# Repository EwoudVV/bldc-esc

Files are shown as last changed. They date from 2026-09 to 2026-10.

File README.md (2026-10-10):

# BLDC ESC

i'm building a small vesc like controller for BLDC and PMSM motors. the first motor is a 26V Groschopp gearmotor, but i want the board to be useful for other motors too. Hall control first, then FOC later

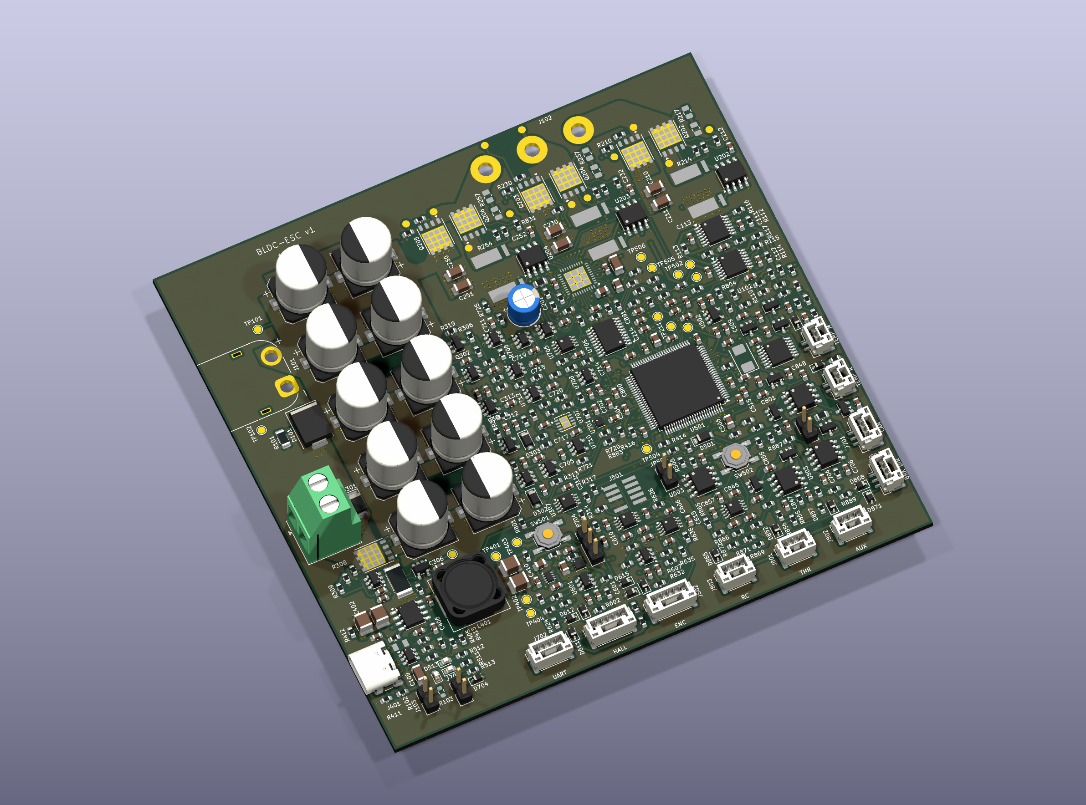
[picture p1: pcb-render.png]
PCB render


## status

the schematic and first placement are done. it's 116 x 112 mm, with all 449 parts on top. the power stage, supplies, gate control, hardware protection, current and voltage sensing, temperature inputs, Hall/encoder inputs and analog controls are routed. the CAN connector and protection, bridge test points, optional snubbers and 8MHz clock are connected too

the USB-C data pins now reach the ESD protection chip in both plug orientations. the USB shield, chassis connector and bond components are connected, and the remaining EEPROM supply pads have power. 20 connections are still open: the long USB data pair, SWD/SWO, UART, CAN logic, EEPROM signals, status LEDs, power-source status and three MCU test points

the board hasn't been built yet. routing, mounting and cooling still need work before ordering it. i'm comparing PCBWay and JLCPCB for bare boards to assemble myself. the fab and exact layer stack aren't confirmed

**don't manufacture the devlog 03 snapshot (`dcad1e4`).** the XT60 connections were backwards in that version. the current design has pad 1 as GND and pad 2 as VBUS

devlogs are on [Half Life](https://halflife.hackclub.com/projects/cmuveje4m009201rvgvsn2jbz) and synced to [JOURNAL.md](https://github.com/EwoudVV/bldc-esc/blob/main/JOURNAL.md)

## hardware

- STM32G474VET6 and DRV8353S gate driver
- six 60V bridge MOSFETs and three 1 milliohm current shunts
- INA241 current sensing, voltage sensing and temperature inputs
- hardware current protection, watchdog and brake chopper
- Hall and encoder inputs, analog throttle, RC PWM and digital controls
- CAN FD, UART, USB-C and SWD
- XT60 power input, MT60 motor pigtail and JST-GH signal connectors

## targets

- 12-30V input, mainly for 6S batteries and 24V systems
- 15A RMS phase current with passive cooling, 20A with extra cooling
- around 40A peak, with the allowed duration still to be worked out
- four layers, with 2 oz outer copper and 1 oz inner copper planned

these current ratings are targets until thermal testing is done

## test motor

Groschopp / Blue-White BL6560-PS2120, P/N 930-23-9002:

- 26V, 0.75A nameplate
- 10W reducer output, 125 RPM, 6.68 in-lb torque
- 20:1 gearbox
- three phase leads and a separate sensor wire bundle

the OEM sensor pinout and motor measurements still need checking

## files

- `bldc-esc.kicad_pro`: open this in KiCad
- `schematic/`: the circuit sheets
- `bldc-esc.kicad_sym` and `bldc-esc.pretty/`: local symbols and footprints
- [bom.csv](bom.csv): component list, including the DNP flags

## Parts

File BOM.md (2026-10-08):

# BLDC-ESC – bill of materials

<!-- Generated by Half Life from project cmuveje4m009201rvgvsn2jbz. Edits here are overwritten on the next sync. -->
<!-- Generated: 1970-01-01T00:00:00.000Z -->

> [!NOTE]
> This parts list is mirrored from [Half Life](https://halflife.hackclub.com). Editing it here will not change the platform's copy, and the next sync overwrites this file.

| Week | Tier | Parts funding |
| --- | --- | --- |
| Week 1 | Tier 3 | $100.00 |

_No parts listed yet._

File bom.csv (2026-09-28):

reference | sheet | value | MPN | manufacturer | footprint | DNP | exclude_from_BOM
J101 | 01_dc_link | XT60PW-M | XT60PW-M | AMASS | Connector_AMASS:AMASS_XT60PW-M_1x02_P7.20mm_Horizontal | false | false
D101 | 01_dc_link | SMCJ30A | SMCJ30A | Littelfuse | Diode_SMD:D_SMC | false | false
C101 | 01_dc_link | 100u 63V | GXC1J101MCW1GS | Nichicon | Capacitor_SMD:CP_Elec_10x12.5 | false | false
C102 | 01_dc_link | 100u 63V | GXC1J101MCW1GS | Nichicon | Capacitor_SMD:CP_Elec_10x12.5 | false | false
C103 | 01_dc_link | 100u 63V | GXC1J101MCW1GS | Nichicon | Capacitor_SMD:CP_Elec_10x12.5 | false | false
C104 | 01_dc_link | 100u 63V | GXC1J101MCW1GS | Nichicon | Capacitor_SMD:CP_Elec_10x12.5 | false | false
C105 | 01_dc_link | 100u 63V | GXC1J101MCW1GS | Nichicon | Capacitor_SMD:CP_Elec_10x12.5 | false | false
C106 | 01_dc_link | 100u 63V | GXC1J101MCW1GS | Nichicon | Capacitor_SMD:CP_Elec_10x12.5 | false | false
C107 | 01_dc_link | 100u 63V | GXC1J101MCW1GS | Nichicon | Capacitor_SMD:CP_Elec_10x12.5 | false | false
C115 | 01_dc_link | 100u 63V | GXC1J101MCW1GS | Nichicon | Capacitor_SMD:CP_Elec_10x12.5 | false | false
C108 | 01_dc_link | 100u 63V | GXC1J101MCW1GS | Nichicon | Capacitor_SMD:CP_Elec_10x12.5 | false | false
C116 | 01_dc_link | 100u 63V | GXC1J101MCW1GS | Nichicon | Capacitor_SMD:CP_Elec_10x12.5 | false | false
R101 | 01_dc_link | 10k | RC1206FR-0710KL | Yageo | Resistor_SMD:R_1206_3216Metric | false | false
J102 | 01_dc_link | MT60 / 12AWG pigtail | MT60-M | AMASS | bldc-esc:MT60_Pigtail_12AWG | false | false
J103 | 01_dc_link | CHASSIS | M20-9990245 | Harwin | Connector_PinHeader_2.54mm:PinHeader_1x02_P2.54mm_Vertical | false | false
R102 | 01_dc_link | 1M | RC0603FR-071ML | Yageo | Resistor_SMD:R_0603_1608Metric | false | false
C109 | 01_dc_link | 4.7n 1kV | C1206C472KDRACTU | KEMET | Capacitor_SMD:C_1206_3216Metric | false | false
R103 | 01_dc_link | 0 | RC0603JR-070RL | Yageo | Resistor_SMD:R_0603_1608Metric | true | false
TP101 | 01_dc_link | VBUS | TESTPOINT |  | TestPoint:TestPoint_Pad_D1.5mm | false | true
TP102 | 01_dc_link | GND | TESTPOINT |  | TestPoint:TestPoint_Pad_D1.5mm | false | true
TP103 | 01_dc_link | PHASE_A | TESTPOINT |  | TestPoint:TestPoint_Pad_D1.5mm | false | true
TP104 | 01_dc_link | PHASE_B | TESTPOINT |  | TestPoint:TestPoint_Pad_D1.5mm | false | true
TP105 | 01_dc_link | PHASE_C | TESTPOINT |  | TestPoint:TestPoint_Pad_D1.5mm | false | true
U201 | 12_gate_driver | DRV8353SRTAT | DRV8353SRTAT | Texas Instruments | bldc-esc:DRV8353_RTA0040B | false | false
R201 | 12_gate_driver | 2.2 | RC0805FR-072R2L | Yageo | Resistor_SMD:R_0805_2012Metric | false | false
C201 | 12_gate_driver | 22u 63V | EEUFC1J220 | Panasonic | Capacitor_THT:CP_Radial_D6.3mm_P2.50mm | false | false
C202 | 12_gate_driver | 100n 100V | C0603C104K1RACTU | KEMET | Capacitor_SMD:C_0603_1608Metric | false | false
C203 | 12_gate_driver | 47n 100V | C0805C473K1RACTU | KEMET | Capacitor_SMD:C_0805_2012Metric | false | false
C204 | 12_gate_driver | 1u 50V | C3216X7R1H105K160AB | TDK | Capacitor_SMD:C_1206_3216Metric | false | false
C205 | 12_gate_driver | 1u 25V | C0805C105K3RACTU | KEMET | Capacitor_SMD:C_0805_2012Metric | false | false
C206 | 12_gate_driver | 1u 16V | C0603C105K4RACTU | KEMET | Capacitor_SMD:C_0603_1608Metric | false | false
C207 | 12_gate_driver | 100n 50V | C0603C104K5RACTU | KEMET | Capacitor_SMD:C_0603_1608Metric | false | false
R202 | 12_gate_driver | 4.7k | RC0603FR-074K7L | Yageo | Resistor_SMD:R_0603_1608Metric | false | false
R203 | 12_gate_driver | 10k | RC0603FR-0710KL | Yageo | Resistor_SMD:R_0603_1608Metric | false | false
R204 | 12_gate_driver | 100k | RC0603FR-07100KL | Yageo | Resistor_SMD:R_0603_1608Metric | false | false
R205 | 12_gate_driver | 10k | RC0603FR-0710KL | Yageo | Resistor_SMD:R_0603_1608Metric | false | false
Q201 | 02_bridge | ISC011N06LM5 | ISC011N06LM5ATMA1 | Infineon | Package_SON:Infineon_PG-TDSON-8_6.15x5.15mm | false | false
Q202 | 02_bridge | ISC011N06LM5 | ISC011N06LM5ATMA1 | Infineon | Package_SON:Infineon_PG-TDSON-8_6.15x5.15mm | false | false
R210 | 02_bridge | 3.3 | RC0603FR-073R3L | Yageo | Resistor_SMD:R_0603_1608Metric | false | false
R211 | 02_bridge | 47k | RC0603FR-0747KL | Yageo | Resistor_SMD:R_0603_1608Metric | false | false
R212 | 02_bridge | 3.3 | RC0603FR-073R3L | Yageo | Resistor_SMD:R_0603_1608Metric | false | false
R213 | 02_bridge | 47k | RC0603FR-0747KL | Yageo | Resistor_SMD:R_0603_1608Metric | false | false
R214 | 02_bridge | 1m 1% 8W | CSS4J-4026R-1L00F | Bourns | bldc-esc:CSS4J_4026 | false | false
C210 | 02_bridge | 1u 100V | C3216X7R2A105K160AA | TDK | Capacitor_SMD:C_1206_3216Metric | false | false
C211 | 02_bridge | 1u 100V | C3216X7R2A105K160AA | TDK | Capacitor_SMD:C_1206_3216Metric | false | false
U202 | 02_bridge | INA241A2IDR | INA241A2IDR | Texas Instruments | Package_SO:SOIC-8_3.9x4.9mm_P1.27mm | false | false
C212 | 02_bridge | 100n 50V | C0603C104K5RACTU | KEMET | Capacitor_SMD:C_0603_1608Metric | false | false
R215 | 02_bridge | 100 | RC0603FR-07100RL | Yageo | Resistor_SMD:R_0603_1608Metric | false | false
C213 | 02_bridge | 1n 50V | C0603C102J5GACTU | KEMET | Capacitor_SMD:C_0603_1608Metric | false | false
TP210 | 02_bridge | I_PHASE_A | TESTPOINT |  | TestPoint:TestPoint_Pad_D1.5mm | false | true
R216 | 02_bridge | 1k | RC0603FR-071KL | Yageo | Resistor_SMD:R_0603_1608Metric | false | false
C214 | 02_bridge | 1n 50V | C0603C102J5GACTU | KEMET | Capacitor_SMD:C_0603_1608Metric | false | false
R217 | 02_bridge | 10 | RC0805FR-0710RL | Yageo | Resistor_SMD:R_0805_2012Metric | true | false
C215 | 02_bridge | 1n 100V | C0805C102J1GACTU | KEMET | Capacitor_SMD:C_0805_2012Metric | true | false
Q203 | 02_bridge | ISC011N06LM5 | ISC011N06LM5ATMA1 | Infineon | Package_SON:Infineon_PG-TDSON-8_6.15x5.15mm | false | false
Q204 | 02_bridge | ISC011N06LM5 | ISC011N06LM5ATMA1 | Infineon | Package_SON:Infineon_PG-TDSON-8_6.15x5.15mm | false | false
R230 | 02_bridge | 3.3 | RC0603FR-073R3L | Yageo | Resistor_SMD:R_0603_1608Metric | false | false
R231 | 02_bridge | 47k | RC0603FR-0747KL | Yageo | Resistor_SMD:R_0603_1608Metric | false | false
R232 | 02_bridge | 3.3 | RC0603FR-073R3L | Yageo | Resistor_SMD:R_0603_1608Metric | false | false
R233 | 02_bridge | 47k | RC0603FR-0747KL | Yageo | Resistor_SMD:R_0603_1608Metric | false | false
R234 | 02_bridge | 1m 1% 8W | CSS4J-4026R-1L00F | Bourns | bldc-esc:CSS4J_4026 | false | false
C230 | 02_bridge | 1u 100V | C3216X7R2A105K160AA | TDK | Capacitor_SMD:C_1206_3216Metric | false | false
C231 | 02_bridge | 1u 100V | C3216X7R2A105K160AA | TDK | Capacitor_SMD:C_1206_3216Metric | false | false
U203 | 02_bridge | INA241A2IDR | INA241A2IDR | Texas Instruments | Package_SO:SOIC-8_3.9x4.9mm_P1.27mm | false | false
C232 | 02_bridge | 100n 50V | C0603C104K5RACTU | KEMET | Capacitor_SMD:C_0603_1608Metric | false | false
R235 | 02_bridge | 100 | RC0603FR-07100RL | Yageo | Resistor_SMD:R_0603_1608Metric | false | false
C233 | 02_bridge | 1n 50V | C0603C102J5GACTU | KEMET | Capacitor_SMD:C_0603_1608Metric | false | false
TP211 | 02_bridge | I_PHASE_B | TESTPOINT |  | TestPoint:TestPoint_Pad_D1.5mm | false | true
R236 | 02_bridge | 1k | RC0603FR-071KL | Yageo | Resistor_SMD:R_0603_1608Metric | false | false
C234 | 02_bridge | 1n 50V | C0603C102J5GACTU | KEMET | Capacitor_SMD:C_0603_1608Metric | false | false
R237 | 02_bridge | 10 | RC0805FR-0710RL | Yageo | Resistor_SMD:R_0805_2012Metric | true | false
C235 | 02_bridge | 1n 100V | C0805C102J1GACTU | KEMET | Capacitor_SMD:C_0805_2012Metric | true | false
Q205 | 02_bridge | ISC011N06LM5 | ISC011N06LM5ATMA1 | Infineon | Package_SON:Infineon_PG-TDSON-8_6.15x5.15mm | false | false
Q206 | 02_bridge | ISC011N06LM5 | ISC011N06LM5ATMA1 | Infineon | Package_SON:Infineon_PG-TDSON-8_6.15x5.15mm | false | false
R250 | 02_bridge | 3.3 | RC0603FR-073R3L | Yageo | Resistor_SMD:R_0603_1608Metric | false | false
R251 | 02_bridge | 47k | RC0603FR-0747KL | Yageo | Resistor_SMD:R_0603_1608Metric | false | false
R252 | 02_bridge | 3.3 | RC0603FR-073R3L | Yageo | Resistor_SMD:R_0603_1608Metric | false | false
R253 | 02_bridge | 47k | RC0603FR-0747KL | Yageo | Resistor_SMD:R_0603_1608Metric | false | false
R254 | 02_bridge | 1m 1% 8W | CSS4J-4026R-1L00F | Bourns | bldc-esc:CSS4J_4026 | false | false
C250 | 02_bridge | 1u 100V | C3216X7R2A105K160AA | TDK | Capacitor_SMD:C_1206_3216Metric | false | false
C251 | 02_bridge | 1u 100V | C3216X7R2A105K160AA | TDK | Capacitor_SMD:C_1206_3216Metric | false | false
U204 | 02_bridge | INA241A2IDR | INA241A2IDR | Texas Instruments | Package_SO:SOIC-8_3.9x4.9mm_P1.27mm | false | false
C252 | 02_bridge | 100n 50V | C0603C104K5RACTU | KEMET | Capacitor_SMD:C_0603_1608Metric | false | false
R255 | 02_bridge | 100 | RC0603FR-07100RL | Yageo | Resistor_SMD:R_0603_1608Metric | false | false
C253 | 02_bridge | 1n 50V | C0603C102J5GACTU | KEMET | Capacitor_SMD:C_0603_1608Metric | false | false
TP212 | 02_bridge | I_PHASE_C | TESTPOINT |  | TestPoint:TestPoint_Pad_D1.5mm | false | true
R256 | 02_bridge | 1k | RC0603FR-071KL | Yageo | Resistor_SMD:R_0603_1608Metric | false | false
C254 | 02_bridge | 1n 50V | C0603C102J5GACTU | KEMET | Capacitor_SMD:C_0603_1608Metric | false | false
R257 | 02_bridge | 10 | RC0805FR-0710RL | Yageo | Resistor_SMD:R_0805_2012Metric | true | false
C255 | 02_bridge | 1n 100V | C0805C102J1GACTU | KEMET | Capacitor_SMD:C_0805_2012Metric | true | false
U401 | 04_power_usb | LM5164DDAR | LM5164DDAR | Texas Instruments | Package_SO:HSOP-8-1EP_3.9x4.9mm_P1.27mm_EP2.41x3.1mm_ThermalVias | false | false
R401 | 04_power_usb | 300k | RC0603FR-07300KL | Yageo | Resistor_SMD:R_0603_1608Metric | false | false
R402 | 04_power_usb | 100k | RC0603FR-07100KL | Yageo | Resistor_SMD:R_0603_1608Metric | false | false
R403 | 04_power_usb | 42.2k | RC0603FR-0742K2L | Yageo | Resistor_SMD:R_0603_1608Metric | false | false
C401 | 04_power_usb | 2.2u 100V | CGA6N3X7R2A225K230AB | TDK | Capacitor_SMD:C_1210_3225Metric | false | false
C402 | 04_power_usb | 2.2u 100V | CGA6N3X7R2A225K230AB | TDK | Capacitor_SMD:C_1210_3225Metric | false | false
C403 | 04_power_usb | 2.2n 50V | C0603C222J5GACTU | KEMET | Capacitor_SMD:C_0603_1608Metric | false | false
L401 | 04_power_usb | 68uH / Isat>=2.3A | MSS1246T-683MLC | Coilcraft | Inductor_SMD:L_Coilcraft_MSS1246T-XXX | false | false
C404 | 04_power_usb | 22u 25V | MSAST32MSB7226KPNB25 | Taiyo Yuden | Capacitor_SMD:C_1210_3225Metric | false | false
C405 | 04_power_usb | 22u 25V | MSAST32MSB7226KPNB25 | Taiyo Yuden | Capacitor_SMD:C_1210_3225Metric | false | false
R404 | 04_power_usb | 324k 0.1% | RT0603BRD07324KL | Yageo | Resistor_SMD:R_0603_1608Metric | false | false
R405 | 04_power_usb | 100k 0.1% | RT0603BRD07100KL | Yageo | Resistor_SMD:R_0603_1608Metric | false | false
R406 | 04_power_usb | 301k | RC0603FR-07301KL | Yageo | Resistor_SMD:R_0603_1608Metric | false | false
C406 | 04_power_usb | 2.2n 50V | C0603C222J5GACTU | KEMET | Capacitor_SMD:C_0603_1608Metric | false | false
C407 | 04_power_usb | 82p 50V | C0603C820J5GACTU | KEMET | Capacitor_SMD:C_0603_1608Metric | false | false
R407 | 04_power_usb | 10k | RC0603FR-0710KL | Yageo | Resistor_SMD:R_0603_1608Metric | false | false
U402 | 04_power_usb | TPS2116DRLR | TPS2116DRLR | Texas Instruments | Package_TO_SOT_SMD:SOT-583-8 | false | false
R408 | 04_power_usb | 300k | RC0603FR-07300KL | Yageo | Resistor_SMD:R_0603_1608Metric | false | false
R409 | 04_power_usb | 100k | RC0603FR-07100KL | Yageo | Resistor_SMD:R_0603_1608Metric | false | false
R410 | 04_power_usb | 10k | RC0603FR-0710KL | Yageo | Resistor_SMD:R_0603_1608Metric | false | false
C408 | 04_power_usb | 1u 16V | C0603C105K4RACTU | KEMET | Capacitor_SMD:C_0603_1608Metric | false | false
C409 | 04_power_usb | 1u 16V | C0603C105K4RACTU | KEMET | Capacitor_SMD:C_0603_1608Metric | false | false
C410 | 04_power_usb | 4.7u 25V | C0805C475K3RACTU | KEMET | Capacitor_SMD:C_0805_2012Metric | false | false
U403 | 04_power_usb | TLV75801PDRVR | TLV75801PDRVR | Texas Instruments | Package_SON:WSON-6-1EP_2x2mm_P0.65mm_EP1x1.6mm | false | false
R417 | 04_power_usb | 51.1k 0.1% | RT0603BRD0751K1L | Yageo | Resistor_SMD:R_0603_1608Metric | false | false
R418 | 04_power_usb | 10k 0.1% | RT0603BRD0710KL | Yageo | Resistor_SMD:R_0603_1608Metric | false | false
C411 | 04_power_usb | 1u 16V | C0603C105K4RACTU | KEMET | Capacitor_SMD:C_0603_1608Metric | false | false
C412 | 04_power_usb | 4.7u 25V | C0805C475K3RACTU | KEMET | Capacitor_SMD:C_0805_2012Metric | false | false
J401 | 13_usb_status | USB4105-GF-A | USB4105-GF-A | GCT | bldc-esc:USB4105_PCBWay | false | false
R411 | 13_usb_status | 5.1k | RC0603FR-075K1L | Yageo | Resistor_SMD:R_0603_1608Metric | false | false
R412 | 13_usb_status | 5.1k | RC0603FR-075K1L | Yageo | Resistor_SMD:R_0603_1608Metric | false | false
F401 | 13_usb_status | 0.5A / 6V | MF-PSMF050X-2 | Bourns | bldc-esc:MF_PSMF0805 | false | false
C413 | 13_usb_status | 100n 50V | C0603C104K5RACTU | KEMET | Capacitor_SMD:C_0603_1608Metric | false | false
U404 | 13_usb_status | USBLC6-2SC6 | USBLC6-2SC6 | STMicroelectronics | Package_TO_SOT_SMD:SOT-23-6 | false | false
R413 | 13_usb_status | 22 | RC0603FR-0722RL | Yageo | Resistor_SMD:R_0603_1608Metric | false | false
R414 | 13_usb_status | 22 | RC0603FR-0722RL | Yageo | Resistor_SMD:R_0603_1608Metric | false | false
R415 | 13_usb_status | 10k | RC0603FR-0710KL | Yageo | Resistor_SMD:R_0603_1608Metric | false | false
R416 | 13_usb_status | 15k | RC0603FR-0715KL | Yageo | Resistor_SMD:R_0603_1608Metric | false | false
TP401 | 13_usb_status | 5V_BUS | TESTPOINT |  | TestPoint:TestPoint_Pad_D1.5mm | false | true
TP402 | 13_usb_status | 5V_SYS | TESTPOINT |  | TestPoint:TestPoint_Pad_D1.5mm | false | true
TP403 | 13_usb_status | 3V3 | TESTPOINT |  | TestPoint:TestPoint_Pad_D1.5mm | false | true
TP404 | 13_usb_status | GND | TESTPOINT |  | TestPoint:TestPoint_Pad_D1.5mm | false | true
U501 | 05_mcu | STM32G474VET6 | STM32G474VET6 | STMicroelectronics | Package_QFP:LQFP-100_14x14mm_P0.5mm | false | false
C501 | 05_mcu | 100n 50V | C0603C104K5RACTU | KEMET | Capacitor_SMD:C_0603_1608Metric | false | false
C502 | 05_mcu | 100n 50V | C0603C104K5RACTU | KEMET | Capacitor_SMD:C_0603_1608Metric | false | false
C503 | 05_mcu | 100n 50V | C0603C104K5RACTU | KEMET | Capacitor_SMD:C_0603_1608Metric | false | false
C504 | 05_mcu | 100n 50V | C0603C104K5RACTU | KEMET | Capacitor_SMD:C_0603_1608Metric | false | false
C505 | 05_mcu | 100n 50V | C0603C104K5RACTU | KEMET | Capacitor_SMD:C_0603_1608Metric | false | false
C506 | 05_mcu | 4.7u 25V | C0805C475K3RACTU | KEMET | Capacitor_SMD:C_0805_2012Metric | false | false
FB501 | 05_mcu | 600R @ 100MHz | BLM18KG601SN1D | Murata | Inductor_SMD:L_0603_1608Metric | false | false
C507 | 05_mcu | 4.7u 25V | C0805C475K3RACTU | KEMET | Capacitor_SMD:C_0805_2012Metric | false | false
C508 | 05_mcu | 100n 50V | C0603C104K5RACTU | KEMET | Capacitor_SMD:C_0603_1608Metric | false | false
U502 | 05_mcu | REF2025AIDDCR | REF2025AIDDCR | Texas Instruments | Package_TO_SOT_SMD:SOT-23-5 | false | false
C509 | 05_mcu | 100n 50V | C0603C104K5RACTU | KEMET | Capacitor_SMD:C_0603_1608Metric | false | false
C510 | 05_mcu | 1u 16V | C0603C105K4RACTU | KEMET | Capacitor_SMD:C_0603_1608Metric | false | false
C511 | 05_mcu | 100n 50V | C0603C104K5RACTU | KEMET | Capacitor_SMD:C_0603_1608Metric | false | false
C512 | 05_mcu | 100n 50V | C0603C104K5RACTU | KEMET | Capacitor_SMD:C_0603_1608Metric | false | false
R501 | 05_mcu | 1k | RC0603FR-071KL | Yageo | Resistor_SMD:R_0603_1608Metric | false | false
D501 | 05_mcu | PMEG2010ER | PMEG2010ER,115 | Nexperia | Diode_SMD:Nexperia_CFP3_SOD-123W | false | false
Y501 | 05_mcu | 8MHz / CL18p | ABM3-8.000MHZ-D2Y-T | Abracon | Crystal:Crystal_SMD_Abracon_ABM3-2Pin_5.0x3.2mm | false | false
R502 | 05_mcu | 0 | RC0603JR-070RL | Yageo | Resistor_SMD:R_0603_1608Metric | false | false
C513 | 05_mcu | 27p 50V | C0603C270J5GACTU | KEMET | Capacitor_SMD:C_0603_1608Metric | false | false
C514 | 05_mcu | 27p 50V | C0603C270J5GACTU | KEMET | Capacitor_SMD:C_0603_1608Metric | false | false
R503 | 05_mcu | 100k | RC0603FR-07100KL | Yageo | Resistor_SMD:R_0603_1608Metric | false | false
JP501 | 05_mcu | BOOT0 | M20-9990245 | Harwin | Connector_PinHeader_2.54mm:PinHeader_1x02_P2.54mm_Vertical | false | false
SW501 | 05_mcu | RESET | TL3342F160QG | E-Switch | Button_Switch_SMD:SW_SPST_TL3342 | false | false
C515 | 05_mcu | 100n 50V | C0603C104K5RACTU | KEMET | Capacitor_SMD:C_0603_1608Metric | false | false
R504 | 05_mcu | 10k | RC0603FR-0710KL | Yageo | Resistor_SMD:R_0603_1608Metric | false | false
SW502 | 05_mcu | USER | TL3342F160QG | E-Switch | Button_Switch_SMD:SW_SPST_TL3342 | false | false
R505 | 05_mcu | 10k | RC0603FR-0710KL | Yageo | Resistor_SMD:R_0603_1608Metric | false | false
J501 | 05_mcu | SWD / KEY 7 | FTSH-105-01-L-DV-007-K | Samtec | bldc-esc:FTSH_105_DV_007_K | false | false
TP501 | 05_mcu | VREF_2V5 | TESTPOINT |  | TestPoint:TestPoint_Pad_D1.5mm | false | true
TP502 | 05_mcu | VBIAS_1V25 | TESTPOINT |  | TestPoint:TestPoint_Pad_D1.5mm | false | true
TP503 | 05_mcu | 3V3_A | TESTPOINT |  | TestPoint:TestPoint_Pad_D1.5mm | false | true
TP504 | 05_mcu | ADC_TRIG_SCOPE | TESTPOINT |  | TestPoint:TestPoint_Pad_D1.5mm | false | true
TP505 | 05_mcu | DAC1_CH1_TP | TESTPOINT |  | TestPoint:TestPoint_Pad_D1.5mm | false | true
TP506 | 05_mcu | DAC1_CH2_TP | TESTPOINT |  | TestPoint:TestPoint_Pad_D1.5mm | false | true
U301 | 03_regen | TLV3011BIDBVR | TLV3011BIDBVR | Texas Instruments | Package_TO_SOT_SMD:SOT-23-6 | false | false
R301 | 03_regen | 100k 0.1% | RT0603BRD07100KL | Yageo | Resistor_SMD:R_0603_1608Metric | false | false
R302 | 03_regen | 100k 0.1% | RT0603BRD07100KL | Yageo | Resistor_SMD:R_0603_1608Metric | false | false
R303 | 03_regen | 8.45k 0.1% | RT0603BRD078K45L | Yageo | Resistor_SMD:R_0603_1608Metric | false | false
R304 | 03_regen | 10k 0.1% | RT0603BRD0710KL | Yageo | Resistor_SMD:R_0603_1608Metric | false | false
R305 | 03_regen | 2.49M | RC0603FR-072M49L | Yageo | Resistor_SMD:R_0603_1608Metric | false | false
R306 | 03_regen | 4.7k | RC0603FR-074K7L | Yageo | Resistor_SMD:R_0603_1608Metric | false | false
C301 | 03_regen | 1n 50V | C0603C102J5GACTU | KEMET | Capacitor_SMD:C_0603_1608Metric | false | false
C302 | 03_regen | 100n 50V | C0603C104K5RACTU | KEMET | Capacitor_SMD:C_0603_1608Metric | false | false
C303 | 03_regen | 100n 50V | C0603C104K5RACTU | KEMET | Capacitor_SMD:C_0603_1608Metric | false | false
U308 | 03_regen | REF2025AIDDCR | REF2025AIDDCR | Texas Instruments | Package_TO_SOT_SMD:SOT-23-5 | false | false
C313 | 03_regen | 100n 50V | C0603C104K5RACTU | KEMET | Capacitor_SMD:C_0603_1608Metric | false | false
C314 | 03_regen | 1u 16V | C0603C105K4RACTU | KEMET | Capacitor_SMD:C_0603_1608Metric | false | false
U302 | 03_regen | UCC27511ADBVR | UCC27511ADBVR | Texas Instruments | Package_TO_SOT_SMD:SOT-23-6 | false | false
R307 | 03_regen | 2.2 | RC0603FR-072R2L | Yageo | Resistor_SMD:R_0603_1608Metric | false | false
R308 | 03_regen | 1 | RC0603FR-071RL | Yageo | Resistor_SMD:R_0603_1608Metric | false | false
Q301 | 03_regen | ISC011N06LM5 | ISC011N06LM5ATMA1 | Infineon | Package_SON:Infineon_PG-TDSON-8_6.15x5.15mm | false | false
R309 | 03_regen | 47k | RC0603FR-0747KL | Yageo | Resistor_SMD:R_0603_1608Metric | false | false
R310 | 03_regen | 3m / 3W | WSLP2512R0030FEA | Vishay | Resistor_SMD:R_2512_6332Metric | false | false
C304 | 03_regen | 100n 50V | C0603C104K5RACTU | KEMET | Capacitor_SMD:C_0603_1608Metric | false | false
C305 | 03_regen | 1u 16V | C0603C105K4RACTU | KEMET | Capacitor_SMD:C_0603_1608Metric | false | false
J301 | 03_regen | DUMP RESISTOR | 1711725 | Phoenix Contact | TerminalBlock_Phoenix:TerminalBlock_Phoenix_MKDS-3-2-5.08_1x02_P5.08mm_Horizontal | false | false
D301 | 03_regen | STPS5H100AF | STPS5H100AF | STMicroelectronics | Diode_SMD:D_SOD-128 | false | false
U303 | 03_regen | INA180A1IDBVR | INA180A1IDBVR | Texas Instruments | Package_TO_SOT_SMD:SOT-23-5 | false | false
C306 | 03_regen | 100n 50V | C0603C104K5RACTU | KEMET | Capacitor_SMD:C_0603_1608Metric | false | false
U304 | 15_regen_safety | TLV3201AIDBVR | TLV3201AIDBVR | Texas Instruments | Package_TO_SOT_SMD:SOT-23-5 | false | false
C307 | 15_regen_safety | 100n 50V | C0603C104K5RACTU | KEMET | Capacitor_SMD:C_0603_1608Metric | false | false
R311 | 15_regen_safety | 10k | RC0603FR-0710KL | Yageo | Resistor_SMD:R_0603_1608Metric | false | false
U305 | 15_regen_safety | TPS3808G50DBVR | TPS3808G50DBVR | Texas Instruments | Package_TO_SOT_SMD:SOT-23-6 | false | false
C308 | 15_regen_safety | 1n 50V | C0603C102J5GACTU | KEMET | Capacitor_SMD:C_0603_1608Metric | false | false
C309 | 15_regen_safety | 100n 50V | C0603C104K5RACTU | KEMET | Capacitor_SMD:C_0603_1608Metric | false | false
R312 | 15_regen_safety | 10k | RC0603FR-0710KL | Yageo | Resistor_SMD:R_0603_1608Metric | false | false
D302 | 15_regen_safety | BAT54H | BAT54H,115 | Nexperia | Diode_SMD:D_SOD-123F | false | false
D303 | 15_regen_safety | BAT54H | BAT54H,115 | Nexperia | Diode_SMD:D_SOD-123F | false | false
R313 | 15_regen_safety | 10k | RC0603FR-0710KL | Yageo | Resistor_SMD:R_0603_1608Metric | false | false
C310 | 15_regen_safety | 10n 50V | C0603C103K5RACTU | KEMET | Capacitor_SMD:C_0603_1608Metric | false | false
U306 | 15_regen_safety | SN74LVC1G17DBVR | SN74LVC1G17DBVR | Texas Instruments | Package_TO_SOT_SMD:SOT-23-5 | false | false
U307 | 15_regen_safety | SN74LVC1G74DCTR | SN74LVC1G74DCTR | Texas Instruments | Package_SO:SSOP-8_2.95x2.8mm_P0.65mm | false | false
R314 | 15_regen_safety | 100k | RC0603FR-07100KL | Yageo | Resistor_SMD:R_0603_1608Metric | false | false
C311 | 15_regen_safety | 100n 50V | C0603C104K5RACTU | KEMET | Capacitor_SMD:C_0603_1608Metric | false | false
R315 | 15_regen_safety | 100k | RC0603FR-07100KL | Yageo | Resistor_SMD:R_0603_1608Metric | false | false
R316 | 15_regen_safety | 150k | RC0603FR-07150KL | Yageo | Resistor_SMD:R_0603_1608Metric | false | false
R317 | 15_regen_safety | 100k | RC0603FR-07100KL | Yageo | Resistor_SMD:R_0603_1608Metric | false | false
R318 | 15_regen_safety | 150k | RC0603FR-07150KL | Yageo | Resistor_SMD:R_0603_1608Metric | false | false
Q302 | 03_regen | 2N7002 | 2N7002P,215 | Nexperia | Package_TO_SOT_SMD:SOT-23 | false | false
R319 | 03_regen | 100k | RC0603FR-07100KL | Yageo | Resistor_SMD:R_0603_1608Metric | false | false
TP301 | 03_regen | DUMP_CURRENT | TESTPOINT |  | TestPoint:TestPoint_Pad_D1.5mm | false | true
R320 | 15_regen_safety | 10k 0.1% | RT0603BRD0710KL | Yageo | Resistor_SMD:R_0603_1608Metric | false | false
R321 | 15_regen_safety | 15k 0.1% | RT0603BRD0715KL | Yageo | Resistor_SMD:R_0603_1608Metric | false | false
C312 | 15_regen_safety | 100p 50V | C0603C101J5GACTU | KEMET | Capacitor_SMD:C_0603_1608Metric | false | false
U601 | 06_sensors | TPS2553DBVR-1 | TPS2553DBVR-1 | Texas Instruments | Package_TO_SOT_SMD:SOT-23-6 | false | false
R601 | 06_sensors | 200k | RC0603FR-07200KL | Yageo | Resistor_SMD:R_0603_1608Metric | false | false
R602 | 06_sensors | 100k | RC0603FR-07100KL | Yageo | Resistor_SMD:R_0603_1608Metric | false | false
R603 | 06_sensors | 10k | RC0603FR-0710KL | Yageo | Resistor_SMD:R_0603_1608Metric | false | false
C601 | 06_sensors | 100n 50V | C0603C104K5RACTU | KEMET | Capacitor_SMD:C_0603_1608Metric | false | false
C602 | 06_sensors | 1u 16V | C0603C105K4RACTU | KEMET | Capacitor_SMD:C_0603_1608Metric | false | false
U602 | 06_sensors | TPS2553DBVR-1 | TPS2553DBVR-1 | Texas Instruments | Package_TO_SOT_SMD:SOT-23-6 | false | false
R605 | 06_sensors | 200k | RC0603FR-07200KL | Yageo | Resistor_SMD:R_0603_1608Metric | false | false
R606 | 06_sensors | 100k | RC0603FR-07100KL | Yageo | Resistor_SMD:R_0603_1608Metric | false | false
R607 | 06_sensors | 10k | RC0603FR-0710KL | Yageo | Resistor_SMD:R_0603_1608Metric | false | false
C603 | 06_sensors | 100n 50V | C0603C104K5RACTU | KEMET | Capacitor_SMD:C_0603_1608Metric | false | false
C604 | 06_sensors | 1u 16V | C0603C105K4RACTU | KEMET | Capacitor_SMD:C_0603_1608Metric | false | false
J601 | 06_sensors | HALL | BM05B-GHS-TBT(LF)(SN) | JST | Connector_JST:JST_GH_BM05B-GHS-TBT_1x05-1MP_P1.25mm_Vertical | false | false
J602 | 06_sensors | ENCODER | BM05B-GHS-TBT(LF)(SN) | JST | Connector_JST:JST_GH_BM05B-GHS-TBT_1x05-1MP_P1.25mm_Vertical | false | false
R620 | 06_sensors | 1k | RC0603FR-071KL | Yageo | Resistor_SMD:R_0603_1608Metric | false | false
R621 | 06_sensors | 10k | RC0603FR-0710KL | Yageo | Resistor_SMD:R_0603_1608Metric | false | false
C610 | 06_sensors | 100p 50V | C0603C101J5GACTU | KEMET | Capacitor_SMD:C_0603_1608Metric | false | false
D610 | 06_sensors | PESD5V0S1BA | PESD5V0S1BA,115 | Nexperia | Diode_SMD:D_SOD-323 | false | false
R623 | 06_sensors | 1k | RC0603FR-071KL | Yageo | Resistor_SMD:R_0603_1608Metric | false | false
R624 | 06_sensors | 10k | RC0603FR-0710KL | Yageo | Resistor_SMD:R_0603_1608Metric | false | false
C611 | 06_sensors | 100p 50V | C0603C101J5GACTU | KEMET | Capacitor_SMD:C_0603_1608Metric | false | false
D611 | 06_sensors | PESD5V0S1BA | PESD5V0S1BA,115 | Nexperia | Diode_SMD:D_SOD-323 | false | false
R626 | 06_sensors | 1k | RC0603FR-071KL | Yageo | Resistor_SMD:R_0603_1608Metric | false | false
R627 | 06_sensors | 10k | RC0603FR-0710KL | Yageo | Resistor_SMD:R_0603_1608Metric | false | false
C612 | 06_sensors | 100p 50V | C0603C101J5GACTU | KEMET | Capacitor_SMD:C_0603_1608Metric | false | false
D612 | 06_sensors | PESD5V0S1BA | PESD5V0S1BA,115 | Nexperia | Diode_SMD:D_SOD-323 | false | false
U603 | 06_sensors | SN74LVC3G17DCTR | SN74LVC3G17DCTR | Texas Instruments | Package_SO:SSOP-8_2.95x2.8mm_P0.65mm | false | false
C605 | 06_sensors | 100n 50V | C0603C104K5RACTU | KEMET | Capacitor_SMD:C_0603_1608Metric | false | false
R632 | 06_sensors | 1k | RC0603FR-071KL | Yageo | Resistor_SMD:R_0603_1608Metric | false | false
R633 | 06_sensors | 10k | RC0603FR-0710KL | Yageo | Resistor_SMD:R_0603_1608Metric | false | false
C613 | 06_sensors | 100p 50V | C0603C101J5GACTU | KEMET | Capacitor_SMD:C_0603_1608Metric | false | false
D613 | 06_sensors | PESD5V0S1BA | PESD5V0S1BA,115 | Nexperia | Diode_SMD:D_SOD-323 | false | false
R635 | 06_sensors | 1k | RC0603FR-071KL | Yageo | Resistor_SMD:R_0603_1608Metric | false | false
R636 | 06_sensors | 10k | RC0603FR-0710KL | Yageo | Resistor_SMD:R_0603_1608Metric | false | false
C614 | 06_sensors | 100p 50V | C0603C101J5GACTU | KEMET | Capacitor_SMD:C_0603_1608Metric | false | false
D614 | 06_sensors | PESD5V0S1BA | PESD5V0S1BA,115 | Nexperia | Diode_SMD:D_SOD-323 | false | false
R638 | 06_sensors | 1k | RC0603FR-071KL | Yageo | Resistor_SMD:R_0603_1608Metric | false | false
R639 | 06_sensors | 10k | RC0603FR-0710KL | Yageo | Resistor_SMD:R_0603_1608Metric | false | false
C615 | 06_sensors | 100p 50V | C0603C101J5GACTU | KEMET | Capacitor_SMD:C_0603_1608Metric | false | false
D615 | 06_sensors | PESD5V0S1BA | PESD5V0S1BA,115 | Nexperia | Diode_SMD:D_SOD-323 | false | false
U604 | 06_sensors | SN74LVC3G17DCTR | SN74LVC3G17DCTR | Texas Instruments | Package_SO:SSOP-8_2.95x2.8mm_P0.65mm | false | false
C606 | 06_sensors | 100n 50V | C0603C104K5RACTU | KEMET | Capacitor_SMD:C_0603_1608Metric | false | false
U701 | 16_supervisor | TPS389033DSER | TPS389033DSER | Texas Instruments | Package_SON:WSON-6_1.5x1.5mm_P0.5mm | false | false
R701 | 16_supervisor | 0 | RC0603JR-070RL | Yageo | Resistor_SMD:R_0603_1608Metric | false | false
C701 | 16_supervisor | 100n 50V | C0603C104K5RACTU | KEMET | Capacitor_SMD:C_0603_1608Metric | false | false
C702 | 16_supervisor | 47n 50V | C0603C473K5RACTU | KEMET | Capacitor_SMD:C_0603_1608Metric | false | false
U702 | 16_supervisor | TPS3431SDRBR | TPS3431SDRBR | Texas Instruments | Package_SON:VSON-8-1EP_3x3mm_P0.65mm_EP1.65x2.4mm | false | false
R702 | 16_supervisor | 10k | RC0603FR-0710KL | Yageo | Resistor_SMD:R_0603_1608Metric | false | false
R703 | 16_supervisor | 0 | RC0603JR-070RL | Yageo | Resistor_SMD:R_0603_1608Metric | false | false
R704 | 16_supervisor | 100k | RC0603FR-07100KL | Yageo | Resistor_SMD:R_0603_1608Metric | false | false
C703 | 16_supervisor | 100n 50V | C0603C104K5RACTU | KEMET | Capacitor_SMD:C_0603_1608Metric | false | false
U703 | 09_safety | SN74LVC1G11DBVR | SN74LVC1G11DBVR | Texas Instruments | Package_TO_SOT_SMD:SOT-23-6 | false | false
U704 | 09_safety | SN74LVC1G11DBVR | SN74LVC1G11DBVR | Texas Instruments | Package_TO_SOT_SMD:SOT-23-6 | false | false
U705 | 09_safety | SN74LVC1G74DCTR | SN74LVC1G74DCTR | Texas Instruments | Package_SO:SSOP-8_2.95x2.8mm_P0.65mm | false | false
R705 | 09_safety | 100k | RC0603FR-07100KL | Yageo | Resistor_SMD:R_0603_1608Metric | false | false
R706 | 09_safety | 10k | RC0603FR-0710KL | Yageo | Resistor_SMD:R_0603_1608Metric | false | false
U706 | 09_safety | SN74LVC244APWR | SN74LVC244APWR | Texas Instruments | Package_SO:TSSOP-20_4.4x6.5mm_P0.65mm | false | false
R710 | 09_safety | 10k | RC0603FR-0710KL | Yageo | Resistor_SMD:R_0603_1608Metric | false | false
R711 | 09_safety | 10k | RC0603FR-0710KL | Yageo | Resistor_SMD:R_0603_1608Metric | false | false
R712 | 09_safety | 10k | RC0603FR-0710KL | Yageo | Resistor_SMD:R_0603_1608Metric | false | false
R713 | 09_safety | 10k | RC0603FR-0710KL | Yageo | Resistor_SMD:R_0603_1608Metric | false | false
R714 | 09_safety | 10k | RC0603FR-0710KL | Yageo | Resistor_SMD:R_0603_1608Metric | false | false
R715 | 09_safety | 10k | RC0603FR-0710KL | Yageo | Resistor_SMD:R_0603_1608Metric | false | false
U707 | 09_safety | SN74LVC1G11DBVR | SN74LVC1G11DBVR | Texas Instruments | Package_TO_SOT_SMD:SOT-23-6 | false | false
R716 | 09_safety | 100k | RC0603FR-07100KL | Yageo | Resistor_SMD:R_0603_1608Metric | false | false
U708 | 09_safety | SN74LVC1G11DBVR | SN74LVC1G11DBVR | Texas Instruments | Package_TO_SOT_SMD:SOT-23-6 | false | false
C711 | 09_safety | 100n 50V | C0603C104K5RACTU | KEMET | Capacitor_SMD:C_0603_1608Metric | false | false
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

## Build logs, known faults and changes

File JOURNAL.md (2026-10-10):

# BLDC-ESC – devlog

<!-- Generated by Half Life from project cmuveje4m009201rvgvsn2jbz. Edits here are overwritten on the next sync. -->
<!-- Generated: 2026-10-10T14:55:08.380Z -->

> [!NOTE]
> This devlog is mirrored from [Half Life](https://halflife.hackclub.com). Editing it here will not change the platform's copy, and the next sync overwrites this file.

> a custom 6s esc!

| Week | Tier | Hours logged | Entries |
| --- | --- | --- | --- |
| Week 1 | Tier 3 | 39.42h | 21 |

## Contents

1. [2026-10-05 – Devlog 01: research and project setup](#2026-10-05-devlog-01-research-and-project-setup)
2. [2026-10-05 – Devlog 02: schematics](#2026-10-05-devlog-02-schematics)
3. [2026-10-05 – Devlog 03: schematic review](#2026-10-05-devlog-03-schematic-review)
4. [2026-10-05 – Devlog 04: reference supply and BOM](#2026-10-05-devlog-04-reference-supply-and-bom)
5. [2026-10-05 – Devlog 05: placement](#2026-10-05-devlog-05-placement)
6. [2026-10-05 – Devlog 06: routing](#2026-10-05-devlog-06-routing)
7. [2026-10-06 – Devlog 07: gate driver and bridge routing](#2026-10-06-devlog-07-gate-driver-and-bridge-routing)
8. [2026-10-07 – Devlog 08: brake and buck routing](#2026-10-07-devlog-08-brake-and-buck-routing)
9. [2026-10-07 – Devlog 09: USB power and the 3V3 supply](#2026-10-07-devlog-09-usb-power-and-the-3v3-supply)
10. [2026-10-07 – Devlog 10: PWM and driver controls](#2026-10-07-devlog-10-pwm-and-driver-controls)
11. [2026-10-08 – Devlog 11: watchdog and safety routing](#2026-10-08-devlog-11-watchdog-and-safety-routing)
12. [2026-10-08 – Devlog 12: current feedback and references](#2026-10-08-devlog-12-current-feedback-and-references)
13. [2026-10-08 – Devlog 13: driver current sensing](#2026-10-08-devlog-13-driver-current-sensing)
14. [2026-10-09 – Devlog 14: voltage and temperature sensing](#2026-10-09-devlog-14-voltage-and-temperature-sensing)
15. [2026-10-09 – Devlog 15: brake controls and power branches](#2026-10-09-devlog-15-brake-controls-and-power-branches)
16. [2026-10-09 – Devlog 16: brake-active status](#2026-10-09-devlog-16-brake-active-status)
17. [2026-10-09 – Devlog 17: Hall, encoder and brake-current inputs](#2026-10-09-devlog-17-hall-encoder-and-brake-current-inputs)
18. [2026-10-10 – Devlog 18: throttle and control inputs](#2026-10-10-devlog-18-throttle-and-control-inputs)
19. [2026-10-10 – Devlog 19: boot controls and local wiring](#2026-10-10-devlog-19-boot-controls-and-local-wiring)
20. [2026-10-10 – Devlog 20: CAN bus wiring](#2026-10-10-devlog-20-can-bus-wiring)
21. [2026-10-10 – Devlog 21: bridge test points and snubbers](#2026-10-10-devlog-21-bridge-test-points-and-snubbers)

## Design

### 2026-10-05 – Devlog 01: research and project setup

**4h**

Devlog 01: research and project setup

Date: Sep 27, 2026
Time spent: 4  hours
Lapse: no lapse

Started the motor controller project for my 26 V, 0.75 A Groschopp / Blue-White gearmotor. i want the board to be useful for bigger motors later too

The current target is 12-30 V input, 15 A RMS phase current with passive cooling, and 20 A with some extra cooling

my choices are an STM32G474, a DRV8353S gate driver, six MOSFETs, and three current shunts. Hall and encoder inputs, CAN, USB, and a brake chopper are planned too. I want to get sensored six step working first, then move on to FOC.

Found Groschopp's standard Hall wiring diagram. The pinout on this OEM motor still needs checking, and the higher ratings of other BL6560 motors don't apply to this winding.

A few stuffs changed when i looked at the datasheets:

- Chose INA241A2 amplifiers for better accuracy at low current.
- Changed the ADC reference to 3.0 V and kept the driver's reference input at 3.3 V.
- Increased the candidate capacitor bank to account for ripple current.
- Calculated that the capacitors only absorb about 0.18 J between 26 V and 31 V. The dump resistor still needs to handle the braking energy.

Set up the repo and KiCad project with seven subsheets. The parts list, source links, calculations, measurement table, and draft 100-pin MCU allocation are in `engineering/`

files from this checkpoint:

architecture

calculations

motor

parts

### 2026-10-05 – Devlog 02: schematics

**8h**

Devlog 02: schematics

Date: Sep 28, 2026
Time spent: 8 hours
Lapse: no lapse

now have the first full schematic done. there's 13 subsheets now because the analog inputs, safety stuff, voltage sensing, current protection, gate driver and USB needed their own pages

The bridge, current sensing, power supplies, mcu, hall and encoder inputs, CAN, USB, and brake chopper are all in there. also assigned the footprints and put them on the pcb. theyre just in a grid for now, no placement or routing yet

A few things changed:

- moved the i2c clock off PB8 because thats also the boot pin
- added a hardware current trip and arm latch, so a fault stops the bridge and it needs to be armed again
- added a service jumper for programming. it turns off the watchdog but also holds the bridge off
- gave the brake chopper its own overcurrent protection
- changed the capacitor bank to 10 matching 100uF hybrids after checking the ripple current sharing
- used bigger packages for some chips because the smaller footprints needed 0.15mm clearance

Made local footprints for the gate driver and shunts too. the generic gate driver footprint had the wrong exposed pad size

went back through the drawings because too much of it was just parts connected by labels. wired the local circuits properly, split the amplifiers and comparators into their individual units, and cleaned up the labels and spacing. its a lot easier to follow the filters and protection circuits now

the first pass was still way too spread out. moved the circuit groups closer together and shortened the wire runs. the input and CAN sheets fit on A4 now, and most of the rest fit on A3. the red crosses are DNP parts, like the optional chassis link and snubbers

ERC has 0 errors and 0 warnings. the exported connections and pcb pad nets were checked too, with no schematic/pcb mismatches

next is going through the power and protection circuits again before layout. the usb connector hole clearance and buck regulator thermal vias still need checking against the fab rules

files from this checkpoint:

01_dc_link

02_bridge

03_regen

04_power_usb

05_mcu

06_sensors

08_analog_inputs

09_safety

### 2026-10-05 – Devlog 03: schematic review

**4h**

Devlog 03: schematic review

Date: Sep 28, 2026

Time spent: 4 hours
Lapse: no lapse

went back through the schematic with the datasheets. found some things that erc wouldnt find

the dump resistor diode had the wrong package assigned, the buck input capacitors needed 1210 footprints instead of 1206, and the crystal family didn't actually support 8MHz. fixed those and some of the part numbers. also changed the 3.3V regulator to the exposed-pad version because the little SOT-23 package would get too hot at the planned load

changed the hardware comparators too. the old ones didnt have a good enough guaranteed low output for the logic gates after them. the reset outputs now connect through 0 ohm links instead of diodes, so they don't lose voltage margin there either

the bridge now checks that the brake chopper is ready before it can turn on. that matters if USB keeps the mcu alive but the bus-powered 5V supply stops working. added dump current telemetry and isolated the hardware fault signals from the mcu pins too. found an annoying STM32 detail where the USB dead-battery pull-down can affect the pin used for the driver fault signal, so that needs to be disabled in firmware

the chopper has its own more accurate reference now. the calculated turn-on range is about 30.7-31.8V, with the nominal point around 31.3V. thats still just the emergency clamp, not a safe charging limit for a 6S battery

added buffers and low-leakage clamps for the external analog and temperature inputs. the NTC conversion also needs to account for the 1k series resistor, otherwise it can read the temperature wrong

using PCBWay for the fab checks. changed the corner shape on the USB connector ground pads to get enough clearance around its locating holes. the buck's 0.2mm thermal vias are okay with the selected rules too. still need the actual 2oz/1oz stackup before working out the USB routing dimensions

split the bigger pages again so everything fits on A3 or A4. there's 16 subsheets now. cleaned up the added buffers, protection circuits and labels, and fixed a project-rule setting that was hiding the wires in exports

ERC is still at 0 errors and 0 warnings. checked the exported connections, a separate set of 425 pin connections, and 4096 combinations of the shutdown logic. the pcb has 444 footprints in the staging grid, with no placement or routing done

stopping here for a review checkpoint. the reference supply headroom still needs a closer look, and the final BOM and connector fit checks aren't finished. the current ratings, regen behavior and fault timing all still need real hardware tests

files from this checkpoint:

review-04

review-05

review-10

review-17

### 2026-10-05 – Devlog 04: reference supply and BOM

**3h**

Devlog 04: reference supply and BOM

Date: Sep 28, 2026

Time spent: 3 hours
Lapse: no lapse

finished checking the reference supply and went through the part numbers and connectors

found a pretty bad mistake with the XT60. the footprint has pad 1 as negative and pad 2 as positive, but the nets were the other way around. fixed that in the schematic and pcb, and added a check against the actual footprint markings. nothing has been built yet. the devlog 03 files should not be used to make a board

the 3V reference didnt have enough guaranteed supply headroom. changed it to 2.5V, with 1.25V for the current sensing. also changed the regulator to an adjustable one set to about 3.36V and used a better supervisor on the analog rail. adjusted the current and voltage thresholds and the throttle dividers to match. the main current amplifiers still use gain 20, but the drivers diagnostic ones need gain 10

checked 112 different part numbers. fixed the missing characters in two TI part numbers and the chassis capacitor's order code. the sub polyfuse was actually an 0805 part, not 1206. the SWD connector now has the proper longer pads and pin 7 missing for the key

ERC has 0 errors and 0 warnings. the connection checks, 426 separate pin checks and 4096 shutdown logic cases pass too. there's 449 footprints on the pcb now. the existing positions stayed where they were and there's still no routing or outline

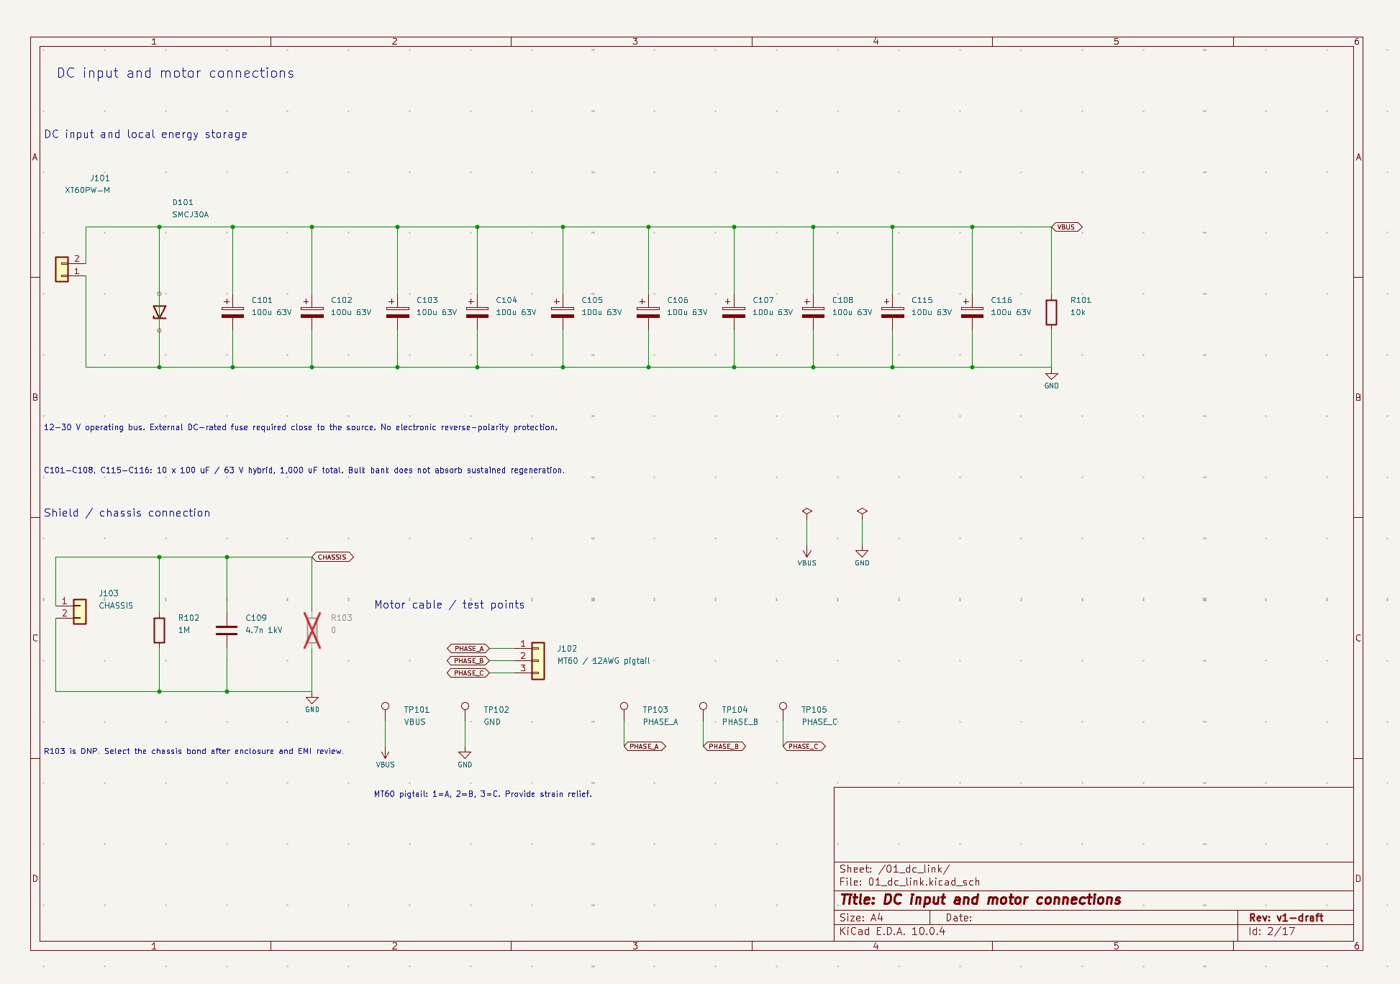
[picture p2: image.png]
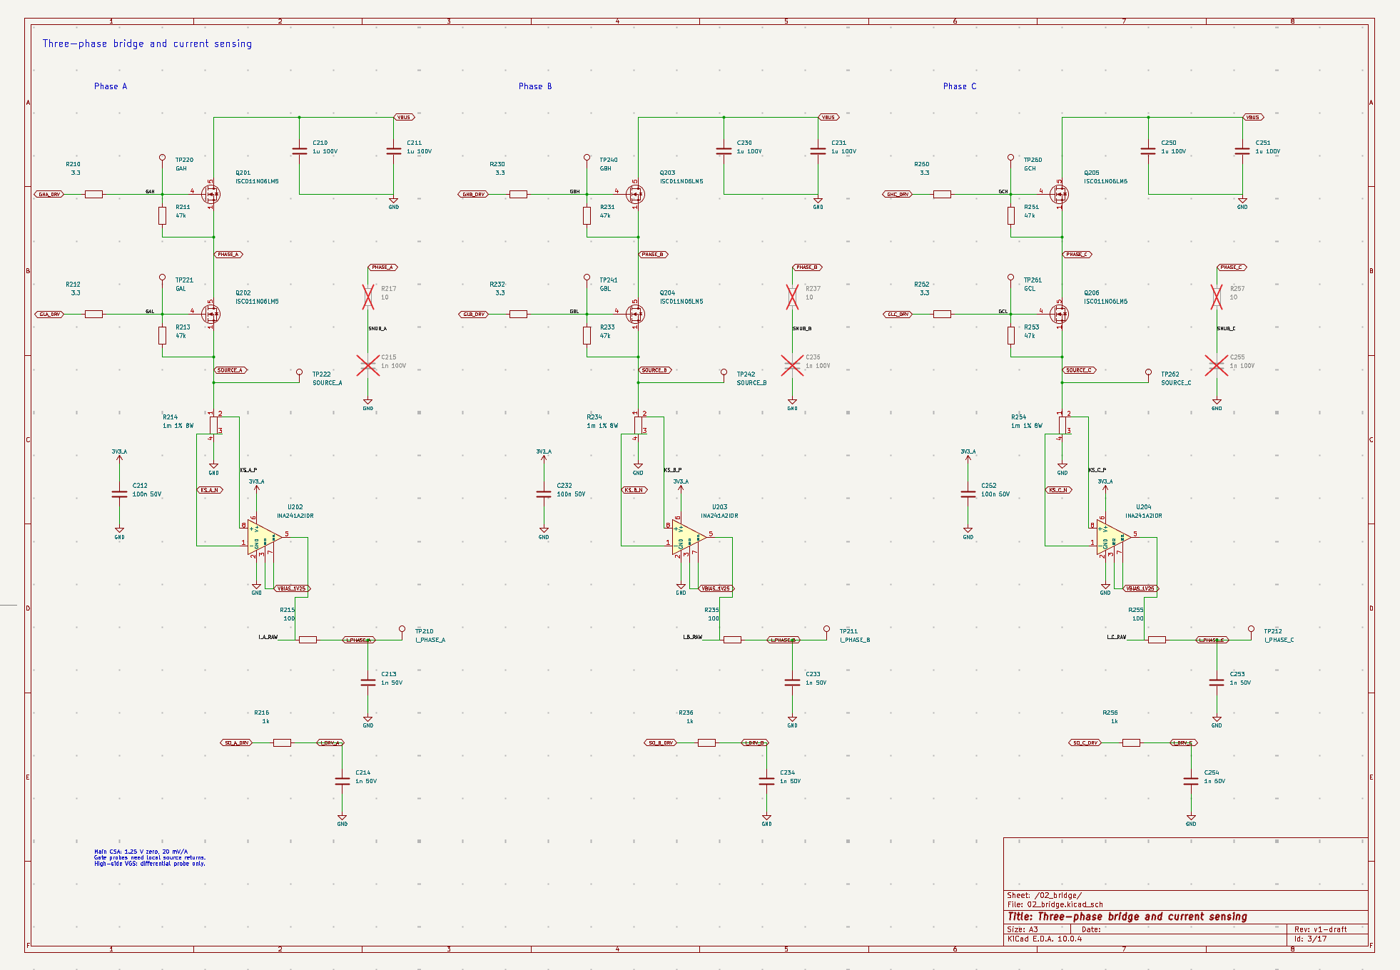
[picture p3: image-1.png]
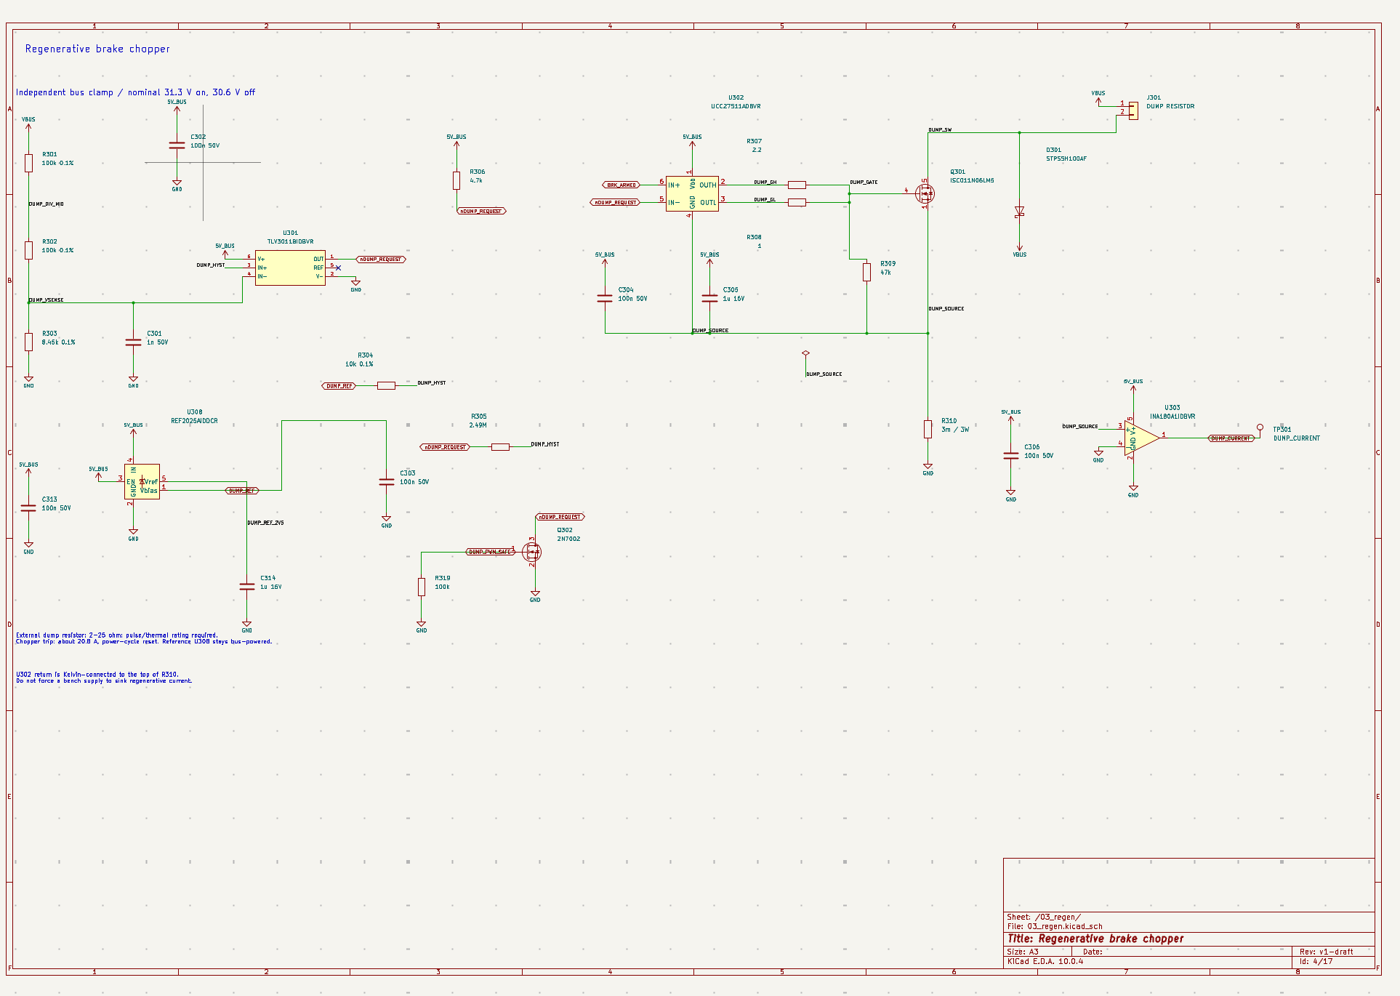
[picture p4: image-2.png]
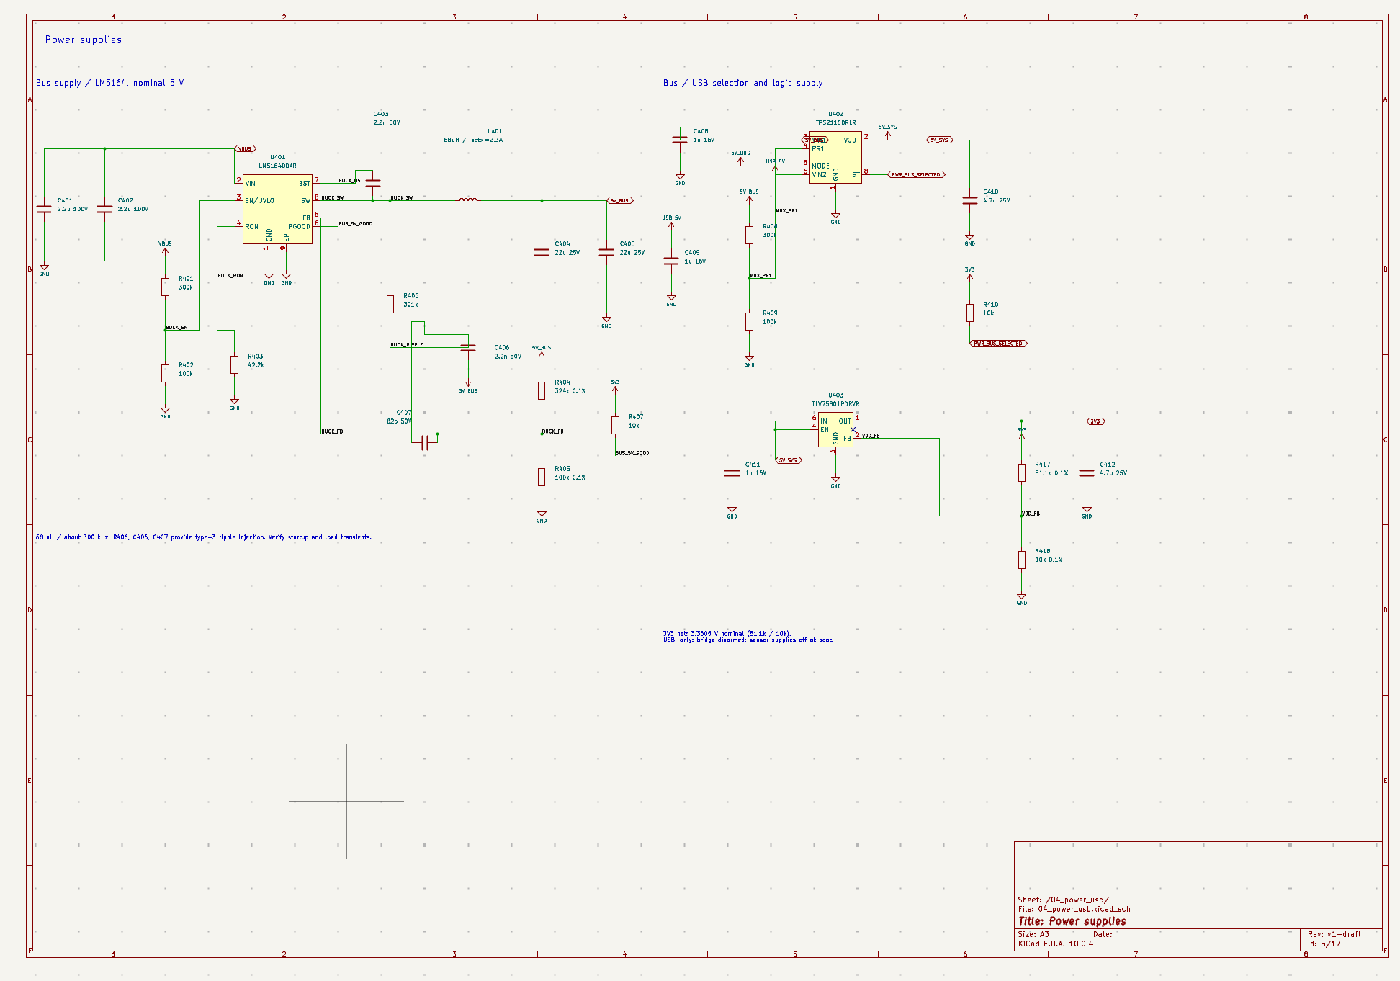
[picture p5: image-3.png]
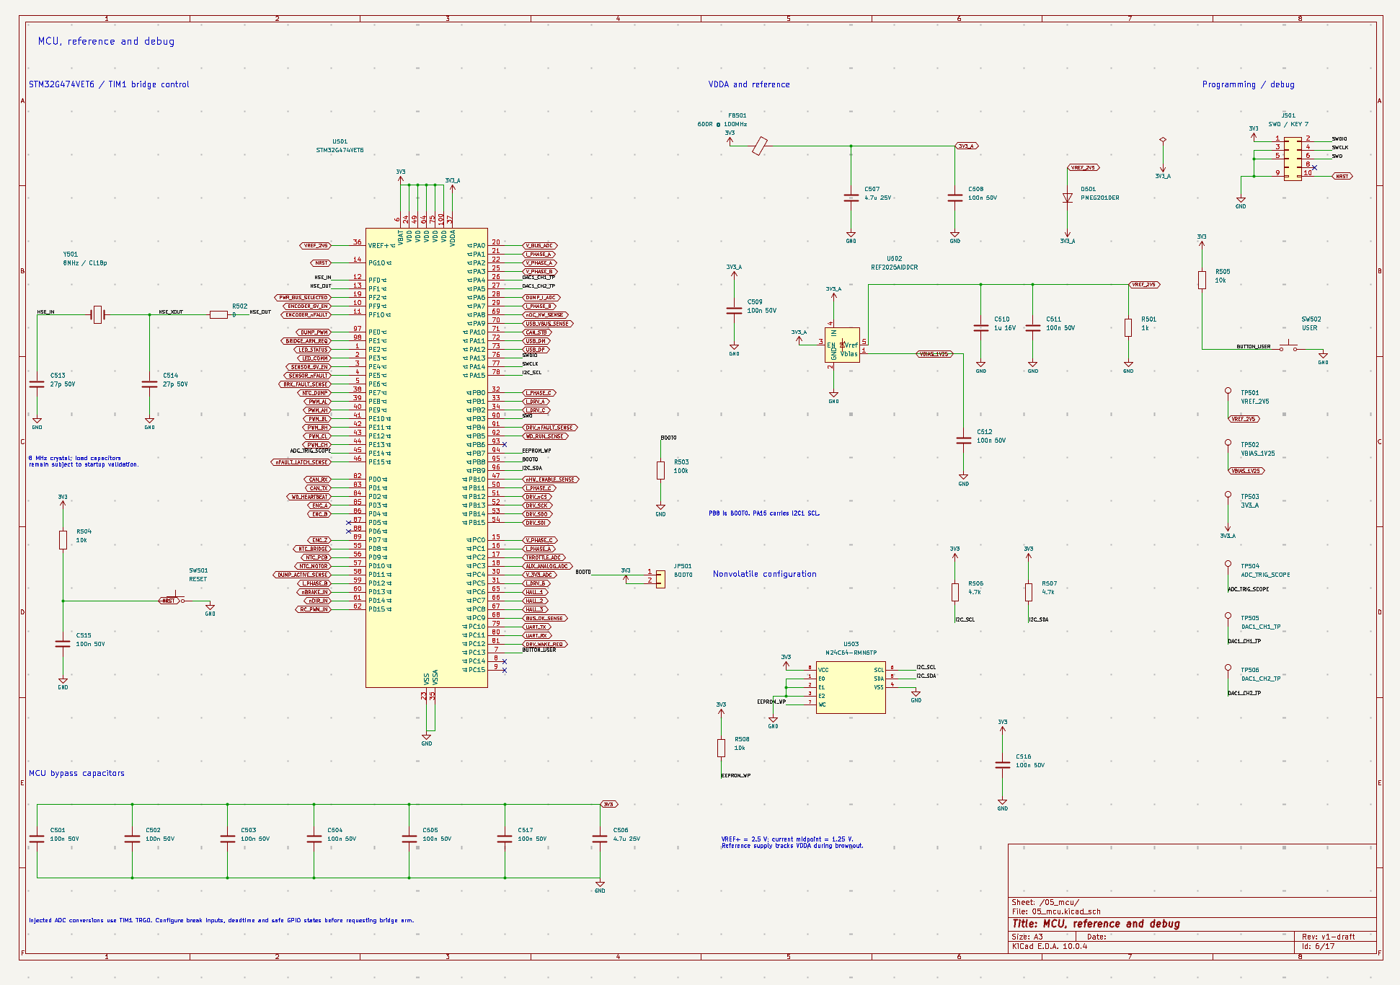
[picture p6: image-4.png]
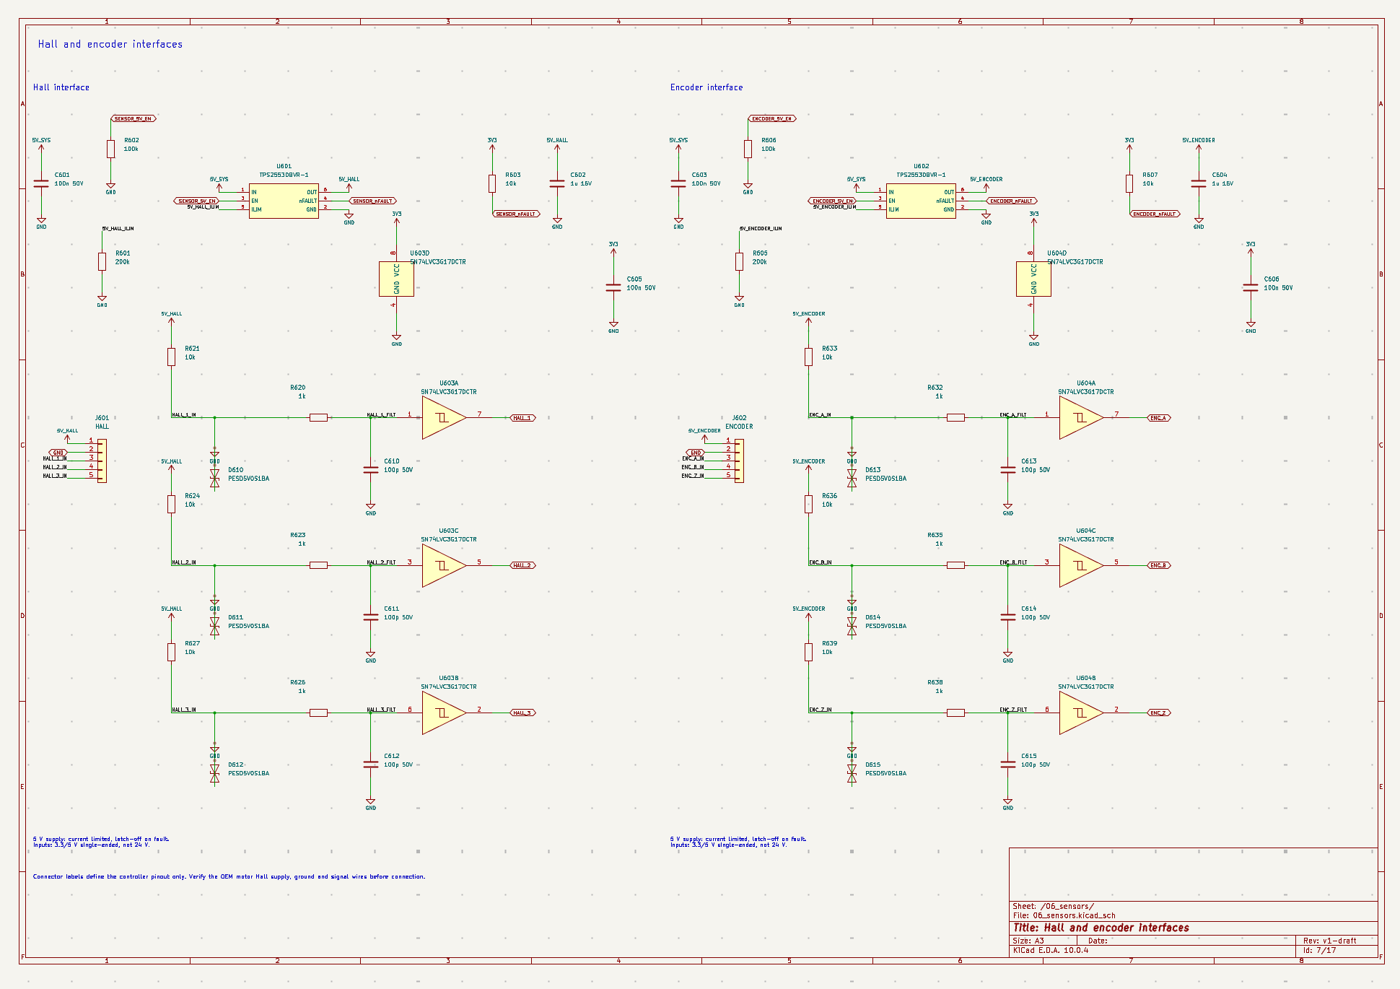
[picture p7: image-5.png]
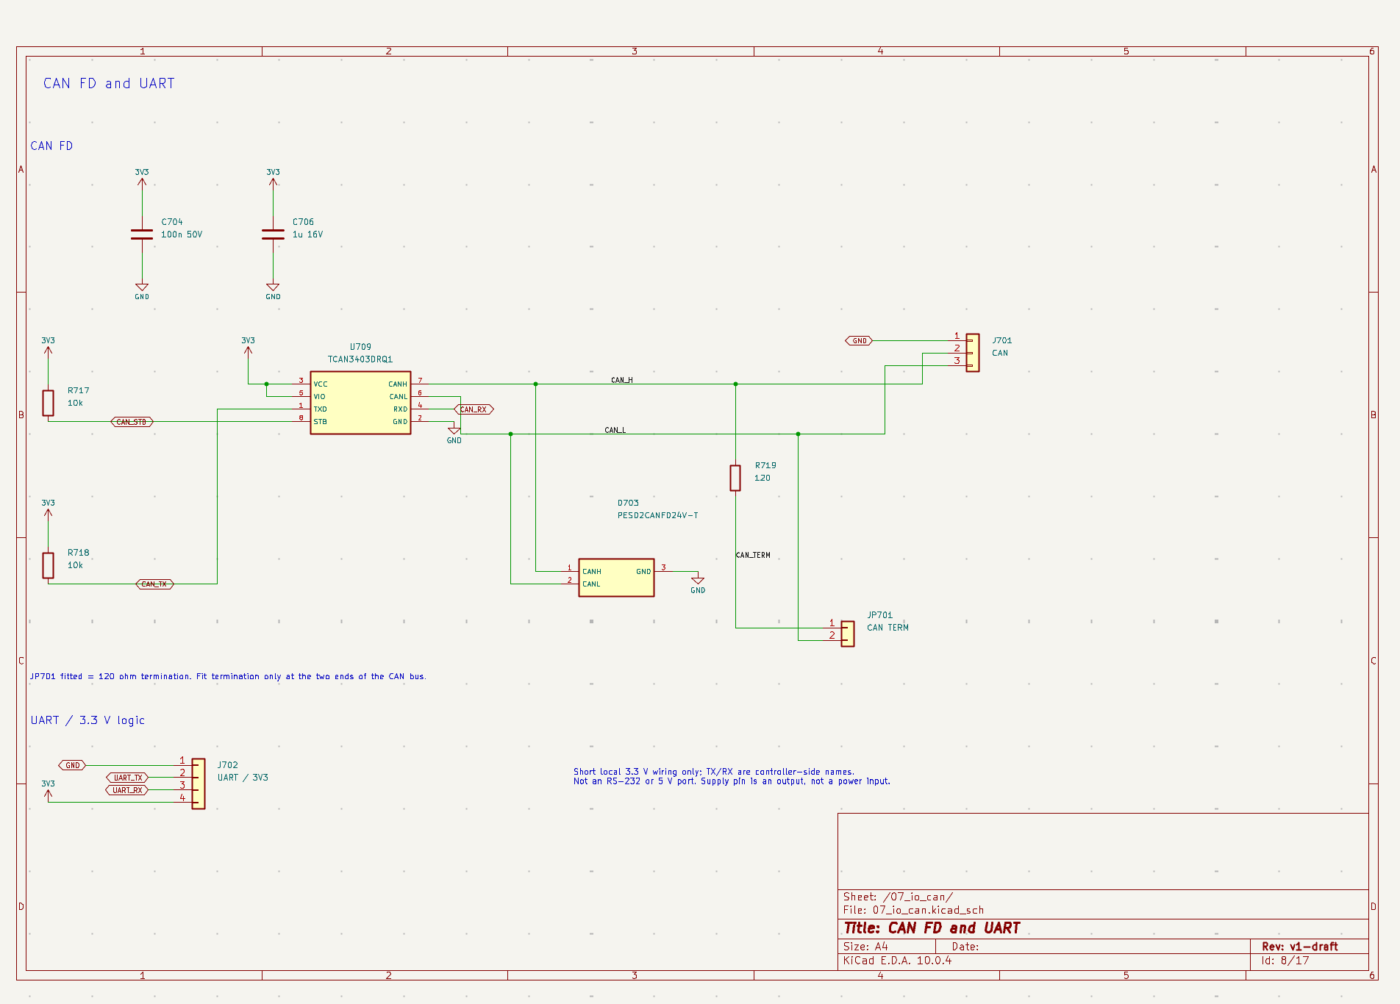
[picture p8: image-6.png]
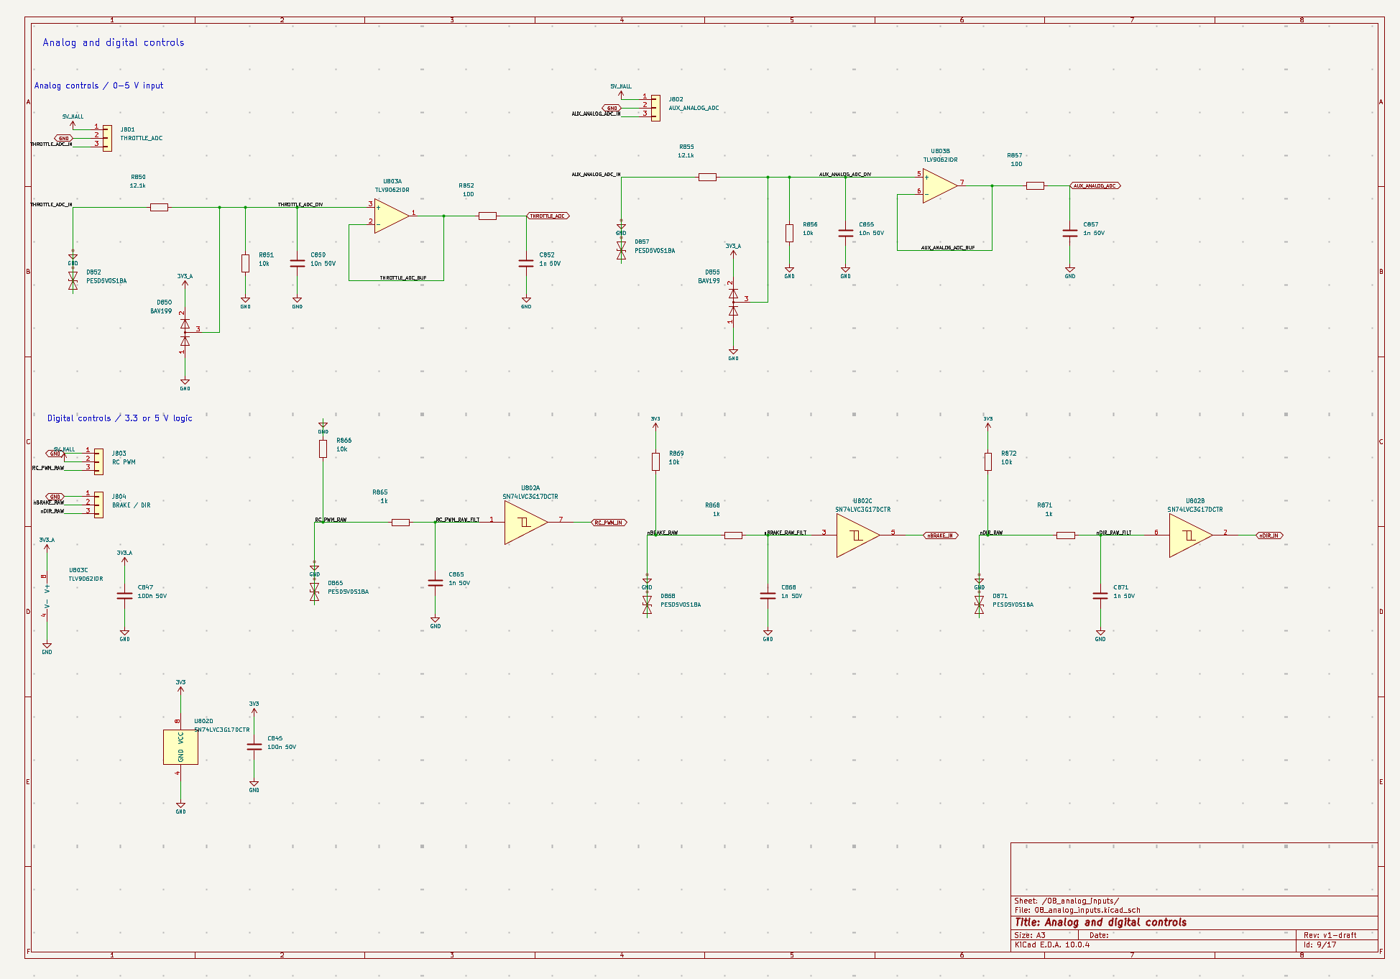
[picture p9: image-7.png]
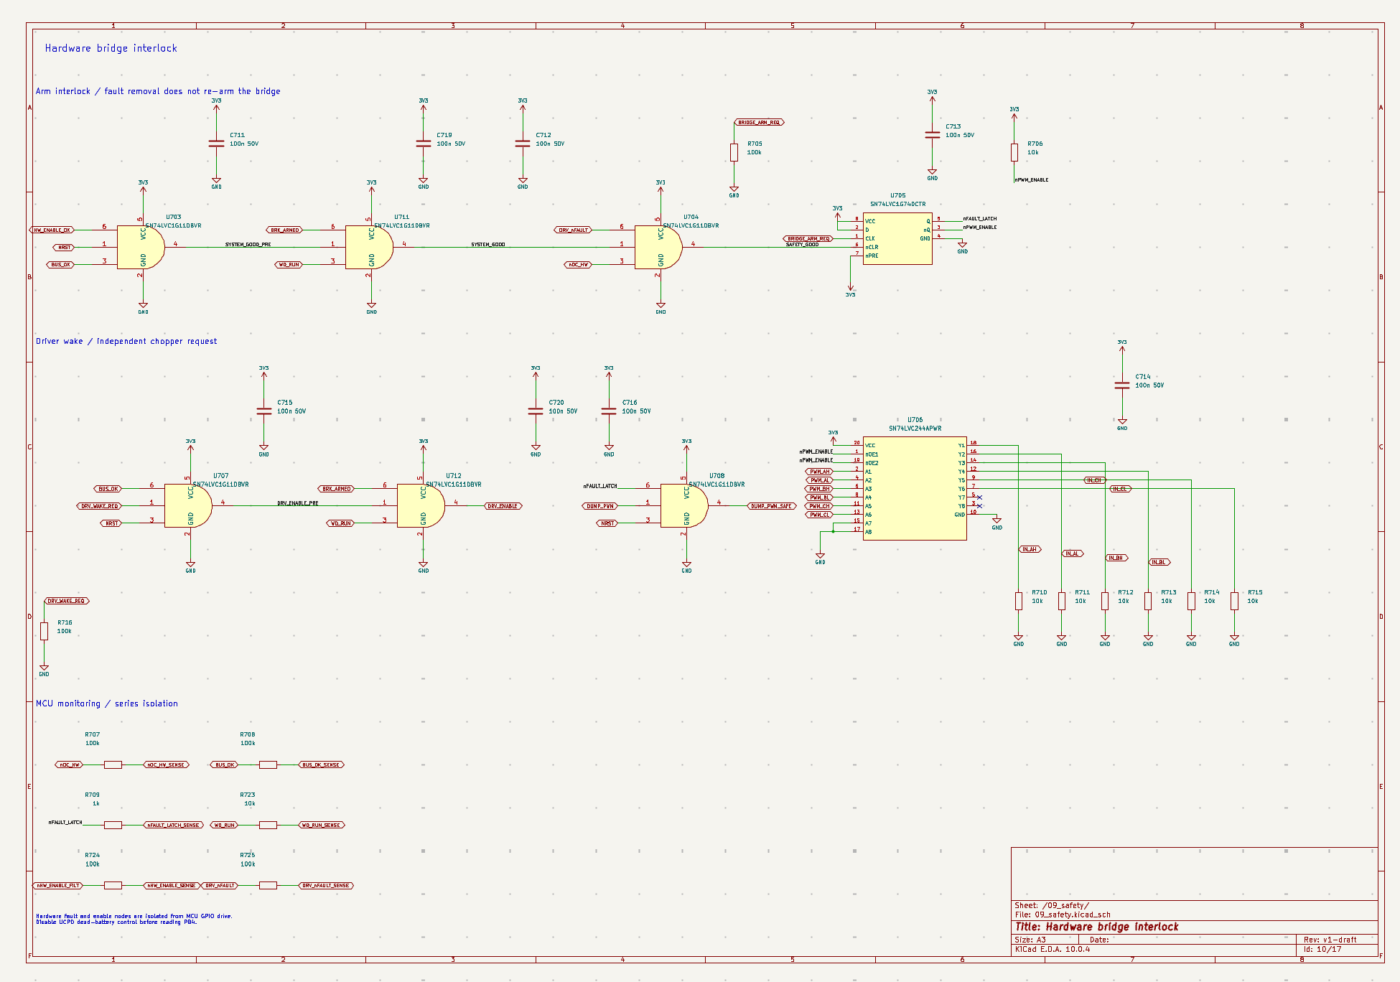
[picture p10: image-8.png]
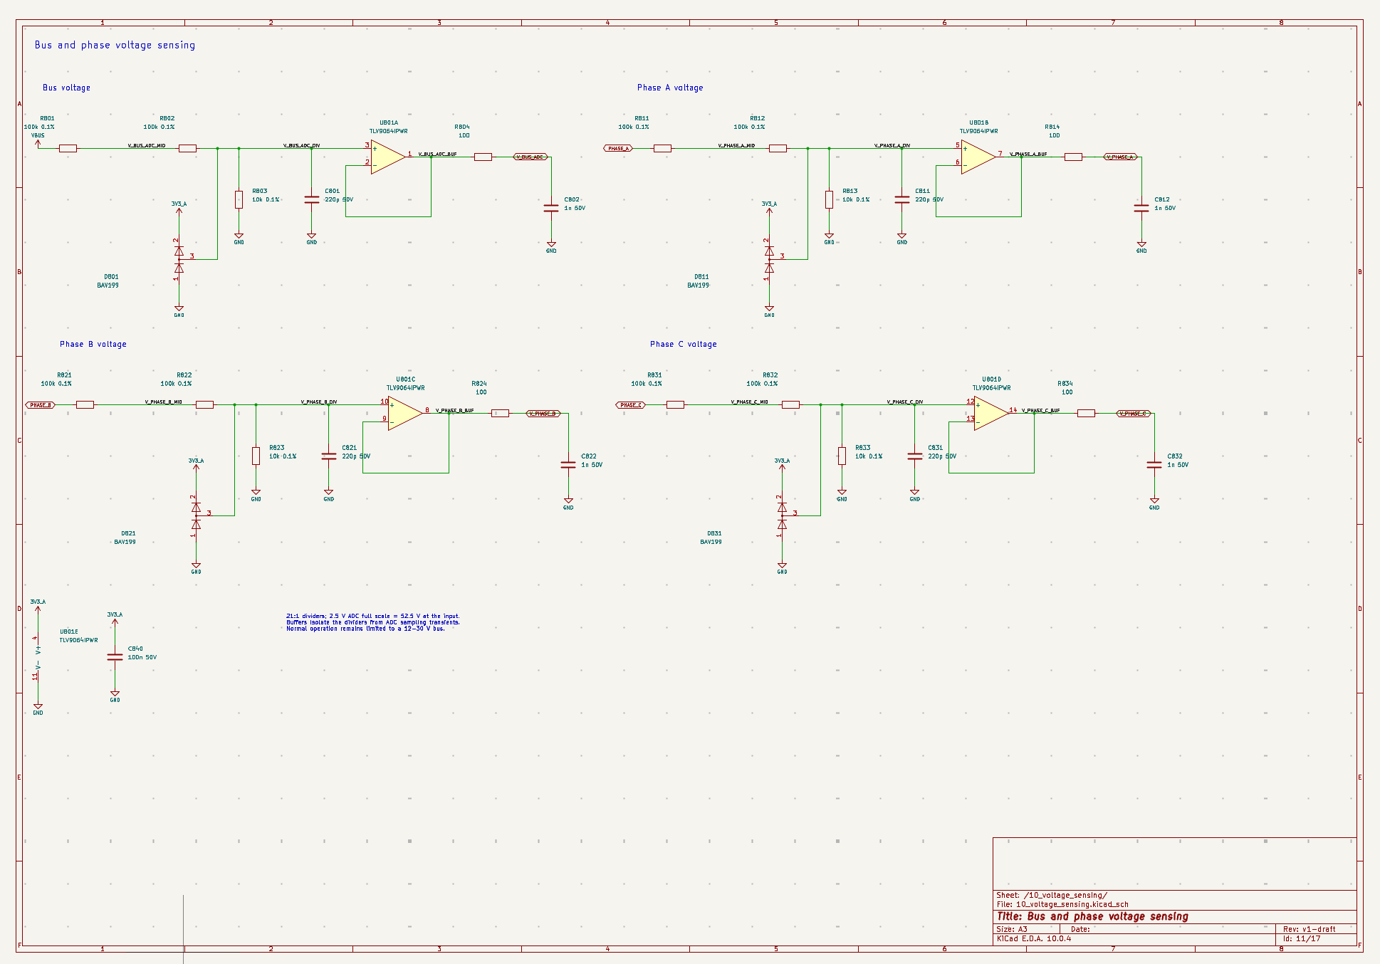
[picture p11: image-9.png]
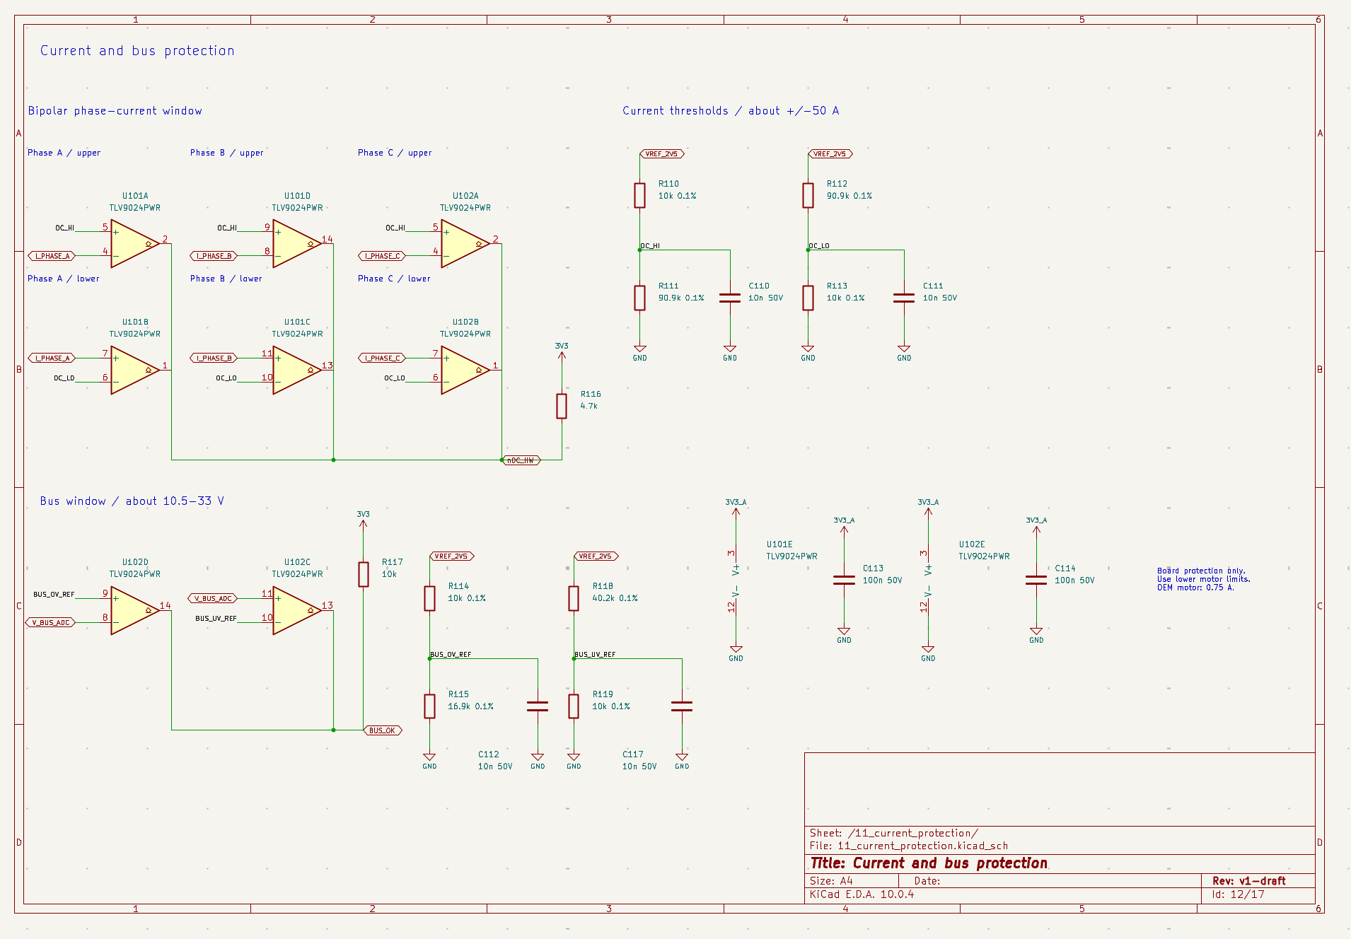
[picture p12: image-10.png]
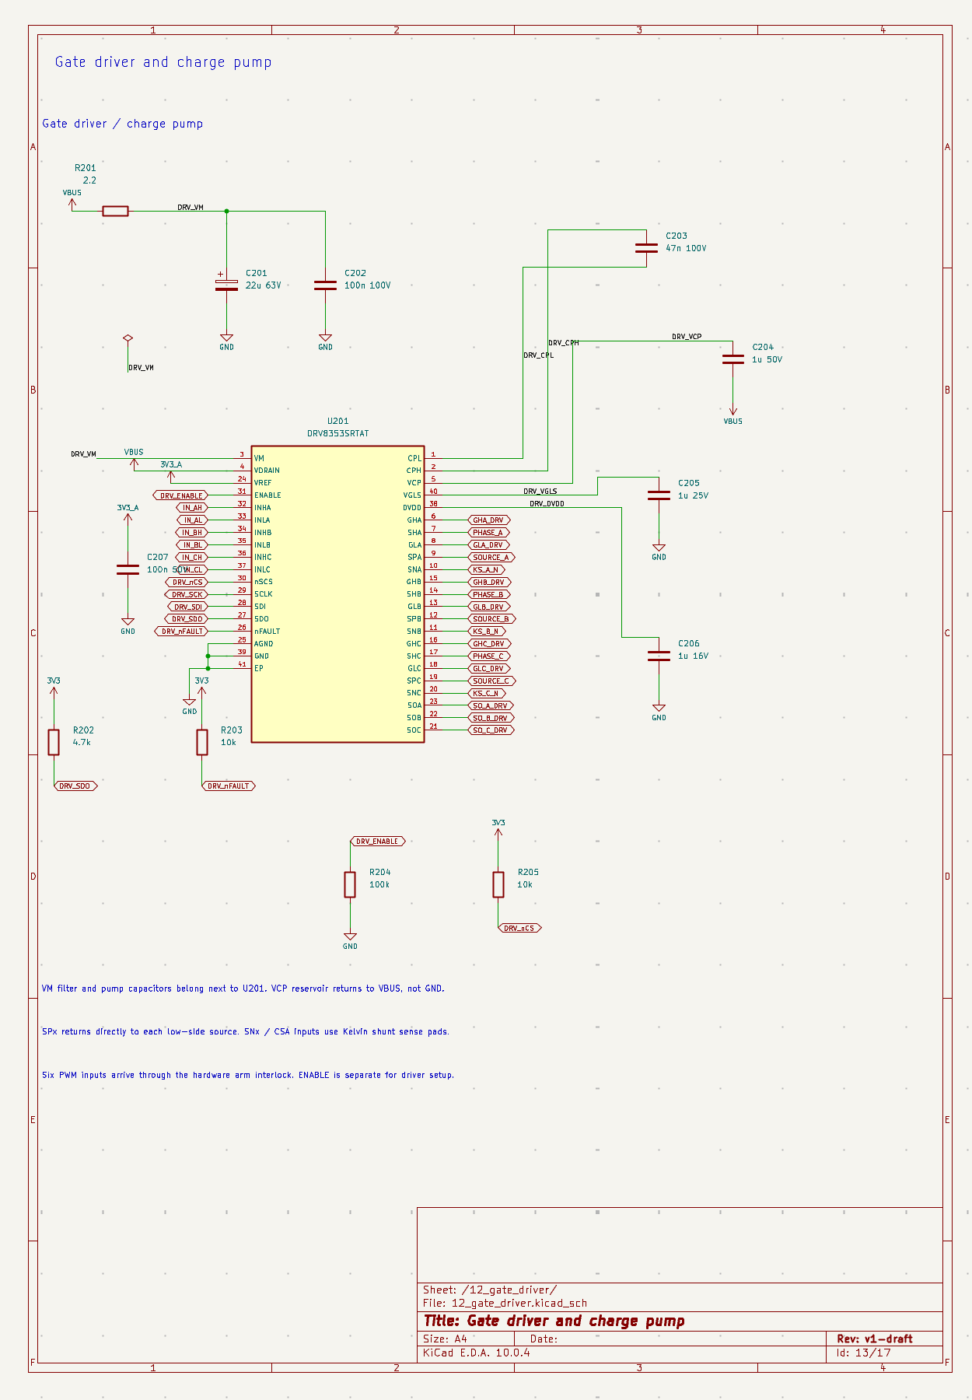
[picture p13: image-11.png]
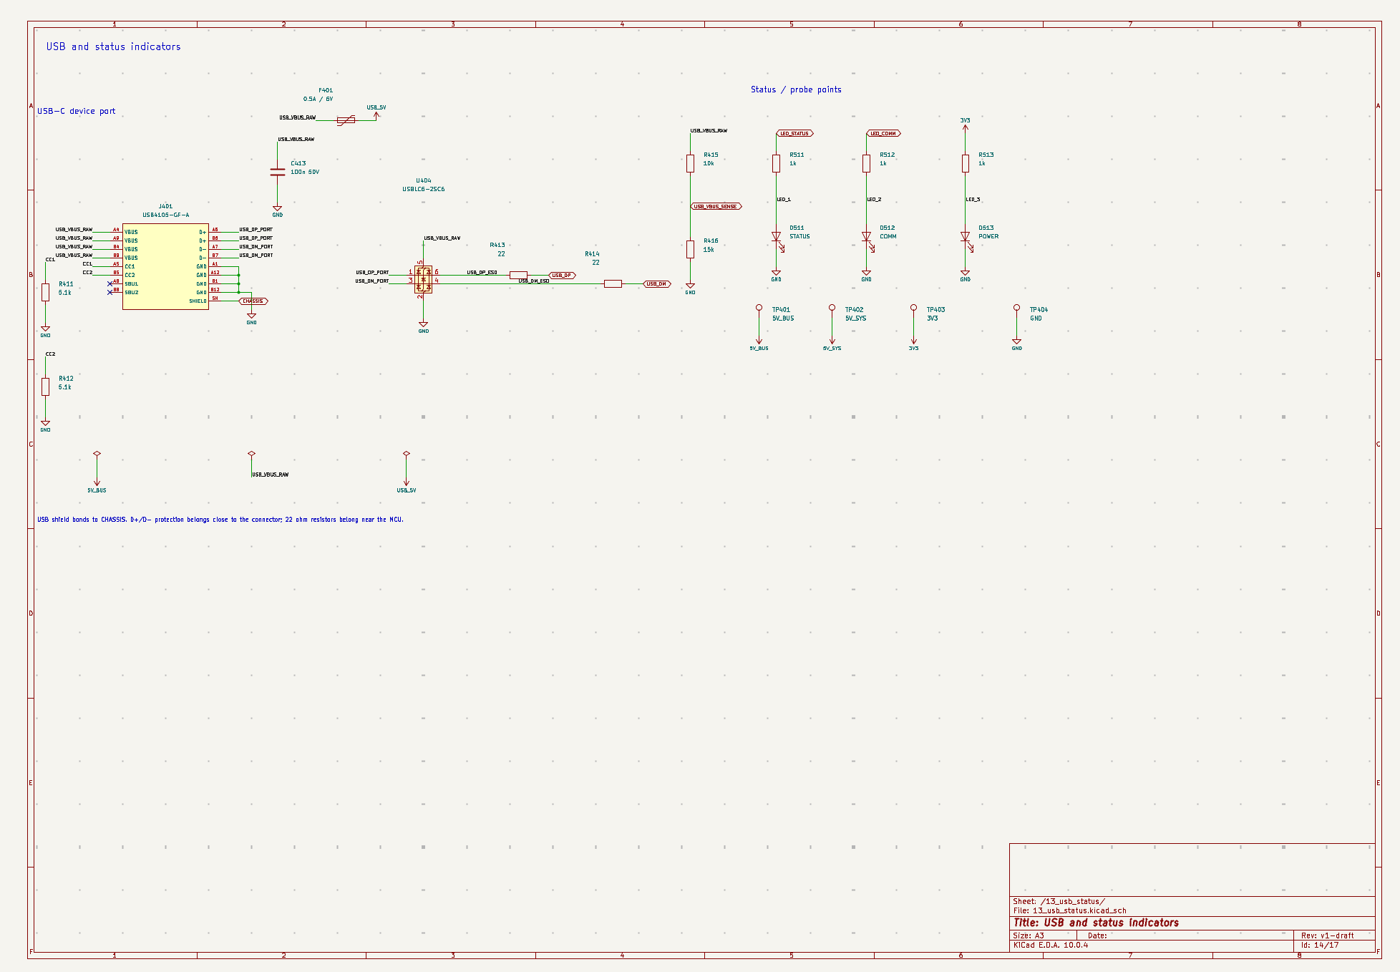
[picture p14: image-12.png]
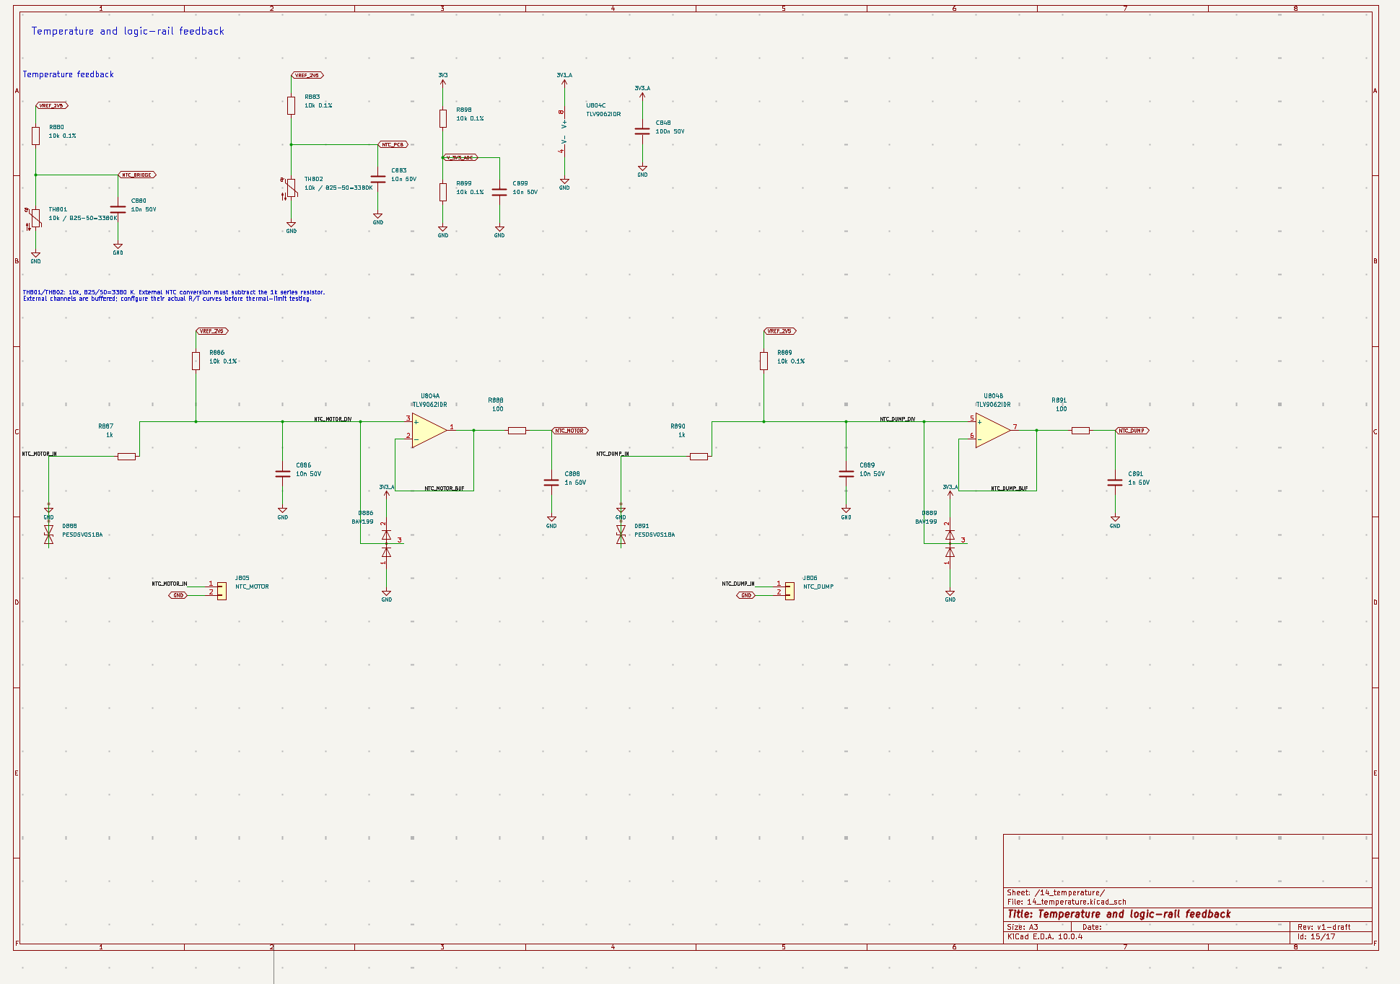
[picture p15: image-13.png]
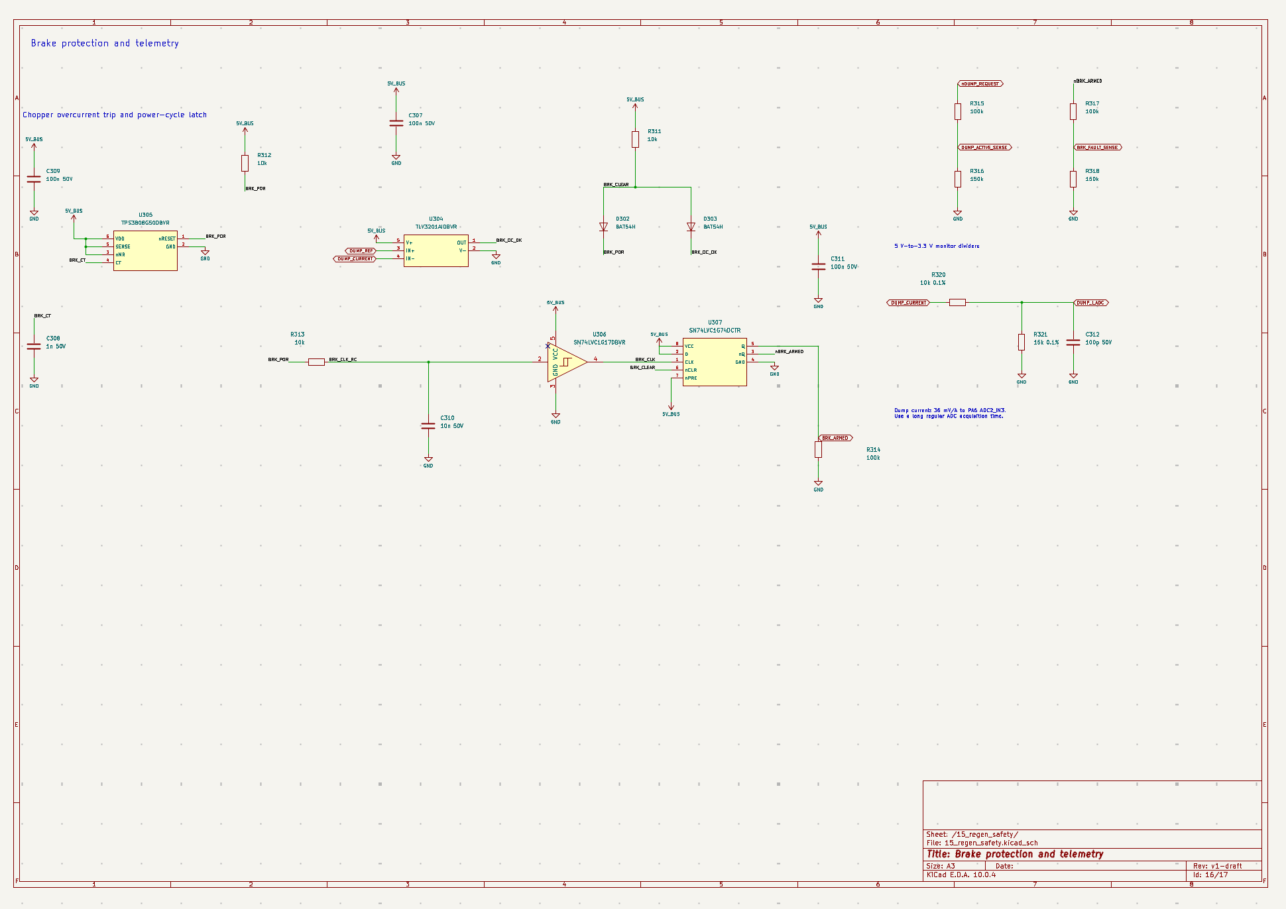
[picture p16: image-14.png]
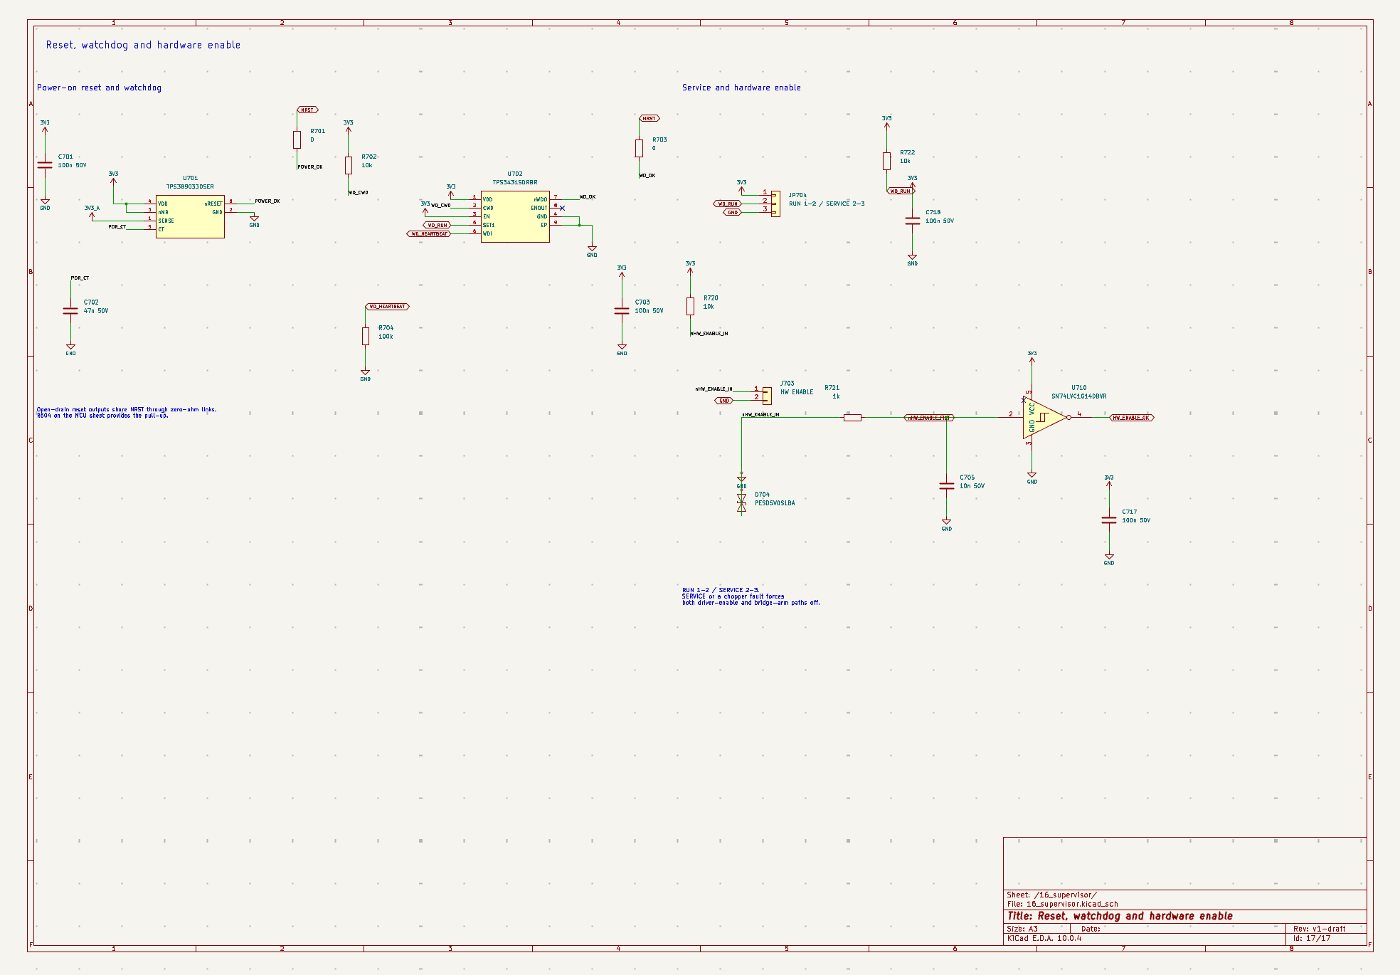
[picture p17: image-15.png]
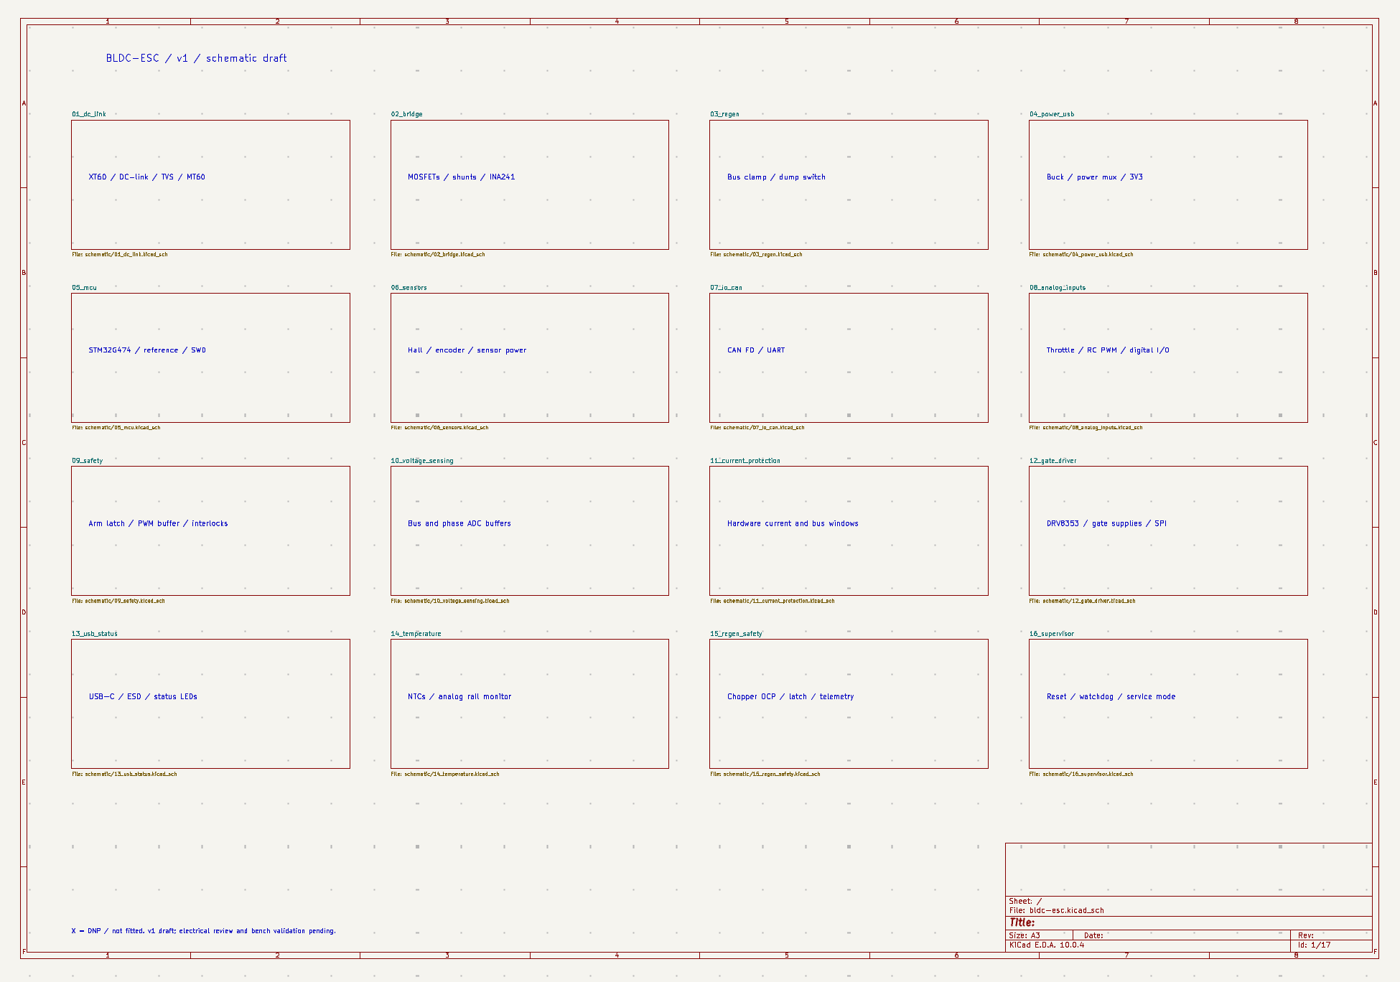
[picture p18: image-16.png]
some images of the schematics:                 

### 2026-10-05 – Devlog 05: placement

**4h**

Devlog 05: placement

Date: Sep 29, 2026

Time spent: 4 hours
Lapse: no lapse

the first placement is done. its 116 x 112 mm right now, with all 449 parts on the top side.

started with the bridge, shunts and local capacitors, then put the gate driver and current amplifiers around them. the amplifiers face the little Kelvin pads on the shunts. moved the driver again after checking the longer gate connections

the capacitor bank is on the left, the motor connections are at the top, and the smaller control connectors go around the bottom and right. the buck is away from the reference and analog inputs. also checked which way the USB and brake connectors face

found a problem before placement: the PCB update had 61 wrong pad assignments. the schematic export was correct, so the pcb was synchronized again before continuing. the old saved board is backed up, and the temporary ground pour is removed

went through the placement renders and DRC a few times. moved the snubbers and voltage pickup resistors closer to their own phases, kept space for the power connections, and cleaned up the reference labels. some of the crowded labels are on the back, but the components are all still on top

there are no courtyard overlaps or copper-clearance errors, and the schematic and PCB match. two bits of the XT60 silkscreen stick over the edge. those still need trimming before making production files

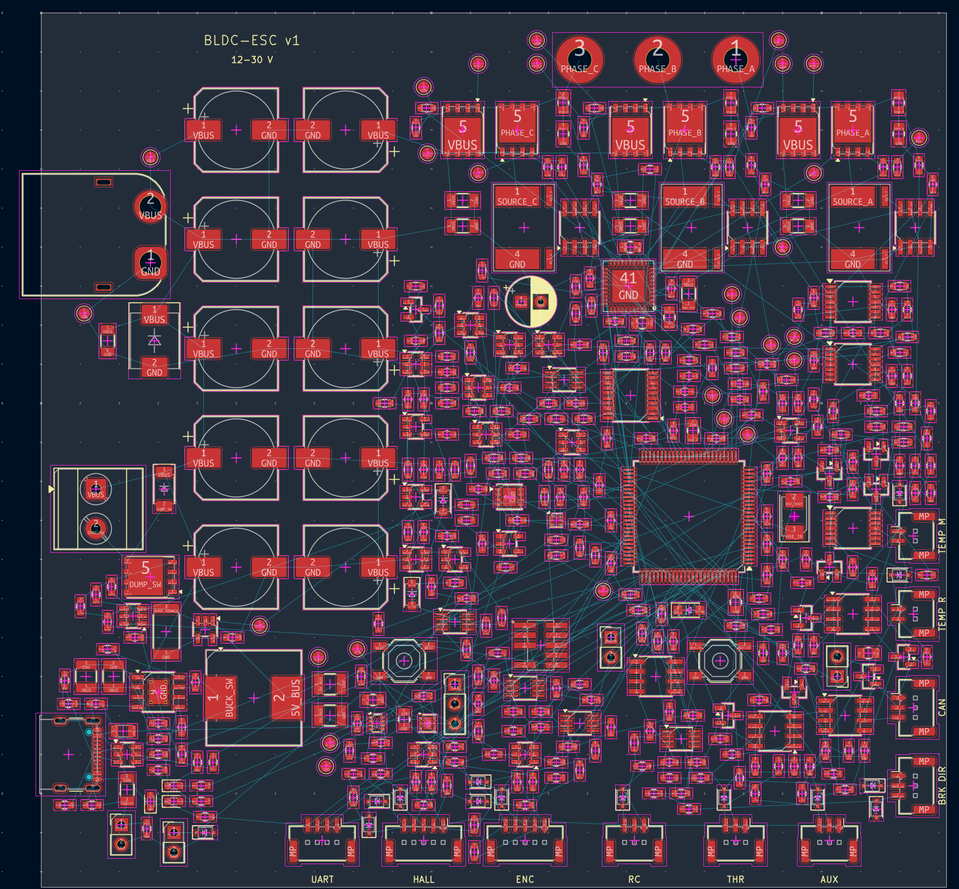
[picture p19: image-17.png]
pcb placemnettn
image: 

placement-3d

placement-bottom

placement-top

### 2026-10-05 – Devlog 06: routing

**0.67h**

Devlog 06: routing

Time spent: 40 mintes
Lapse: [lapse](https://lapse.hackclub.com/timelapse/QfEX7GQmGbGK)

routed the stm32 fanout, and some power stuff

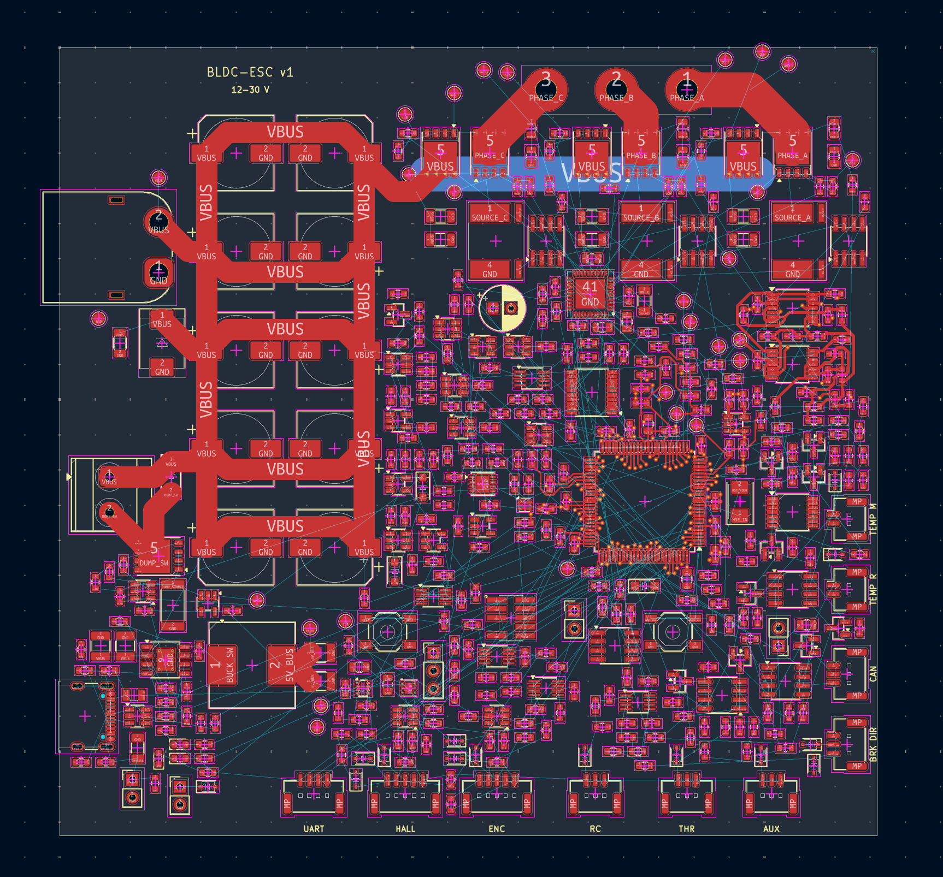
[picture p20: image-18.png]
image: 

this is from the Sep 29 routing checkpoint. the screenshots show the full board and a closer look at the stm32 area.

routing-detail

### 2026-10-06 – Devlog 07: gate driver and bridge routing

**2h**

Devlog 07: gate driver and bridge routing

got the gate driver connected to all six MOSFET gates, along with the charge-pump and bypass capacitors. moved a few nearby parts to make room for the escapes. the earlier stm32 routing stayed where it was

kept the gate traces close to their source returns. most of the longer runs use an inner layer. the returns go back to the MOSFET source pads, and VDRAIN has its own pickup from a high-side drain

then worked on the bridge power paths. connected each high-side source to its low-side drain, and each low-side source to its shunt. widened the DC-link rails on both outer layers and connected the bulk and local bypass capacitors

added groups of vias at the capacitor pads, drains and shunt ground returns. the middle phase was tighter around the thermistor and gate traces, so some of its drain vias sit beside the MOSFET. kept the sense traces separate from the power pours

the new copper squeezed a few ground connections. fixed those with short traces and vias, then refilled the planes and went through DRC again. no new clearance errors or shorts. the old warnings still need cleaning up

the connection checks pass and the pcb nets still match the schematic. checked the power paths with the thin sense traces removed from a copy too, to make sure they weren't carrying the connection. there are still 589 unrouted connections

next are the brake and buck power loops, then the remaining signals. nothing has been built or powered yet

gate-pairs

bridge-power

dc-link-power

### 2026-10-07 – Devlog 08: brake and buck routing

**1h**

Devlog 08: brake and buck routing

routed the brake power path from the resistor connector through the MOSFET and shunt. added copper and stitching vias around the supply, drain and shunt return

the brake gate driver returns to the MOSFET source. kept that return beside the gate trace on an inner layer, and connected the separate turn-on and turn-off resistors. moved one bypass capacitor next to the other one

took separate sense traces from both ends of the brake shunt. the negative one is on the GND net, so added a small pour keepout to stop it from joining the plane before it reaches the shunt

then routed the buck input capacitors, bootstrap capacitor, inductor and output capacitors. moved the timing resistor closer to the regulator and the ripple-injection resistor closer to the switch node

the voltage feedback picks up at the output capacitor separately from the 5V load feed. kept the feedback away from the switch copper and routed the longer sense connection on the back. the 5V output now reaches the brake driver and its current amplifier too

DRC caught a crossing near the brake gate resistors, a 5V trace over a ground via and a few squeezed ground connections. fixed those and went through the filled copper again. the original 95 warnings are still there, with no new clearance errors or shorts

next are the 5V source mux and 3V3 supply, then the driver control signals and remaining interfaces. still a lot of routing to do, and nothing has been built or powered yet

brake-routing

buck-routing

### 2026-10-07 – Devlog 09: USB power and the 3V3 supply

**1h**

Devlog 09: USB power and the 3V3 supply

connected the USB power pins through the fuse to the power mux. routed both CC pull-downs too, along with the bypass capacitor and the USB protection chip's supply

the buck's 5V rail feeds the other mux input. connected the priority divider, mode pin and source-status pull-up, then joined the two output pins and routed 5V_SYS to the regulator

moved the regulator's feedback resistors into the space above it. kept the existing values, so the rail is still set to about 3.36V. connected its input, enable, output capacitor and the existing inner 3V3 plane

put the thermal vias beside the exposed pad, following the datasheet's warning about solder wicking. kept the DNC pin open. the 5V_SYS and 3V3 test points are connected now too

went through the filled copper and DRC again. moved a few vias around the existing buck wiring and cleared the reference labels from the moved resistors. no new clearance errors or shorts; the original 95 warnings still need work

next are the gate-driver control signals and remaining peripheral connections. source switching, voltage regulation and temperatures still need checking on a real board

usb-power

logic-power

### 2026-10-07 – Devlog 10: PWM and driver controls

**1h**

Devlog 10: PWM and driver controls

routed all six PWM channels from the stm32 to the buffer, then from the buffer to the gate driver and pull-down resistors. connected both buffer enable pins to the latch output too

the SPI lines now run between the existing MCU escape vias and the driver. connected the SDO and chip-select pull-ups, the driver enable line, and the fault output to the safety logic. the separate fault-sense trace reaches the MCU through its resistor

the bottom row of driver pins was cramped. moved the DVDD capacitor and enable pull-down to make room for a staggered fanout. rerouted the capacitor connections and a short section of the VM supply. the gate and source-return traces stayed where they were

added the 3V3 feeds for the buffer and pull-ups, plus direct ground connections. put ground vias near the signal layer changes where there wasn't already one close by

DRC caught a capacitor too close to a ground via, some courtyard overlaps and incomplete ground thermals. fixed those and checked the filled copper again. the connection checks pass, with no new DRC findings. 84 old warnings remain

there are 480 unrouted connections left, down from 520. next are the remaining safety logic, diagnostic sense branches and power connections. nothing has been built or powered yet

driver-detail

controls-overview

### 2026-10-08 – Devlog 11: watchdog and safety routing

**1h**

Devlog 11: watchdog and safety routing

routed the watchdog, reset links, hardware enable and arm latch. the MCU heartbeat, wake and arm signals now reach the safety logic, and the fault/status lines come back to the MCU. the dump PWM command is connected through its safety gate too

also connected the main filtered 3V3_A feed and the local supply branches around the supervisor and logic. checking the filled copper turned up a few isolated ground and 3V3 areas, so i added short connections and ground vias where they were needed. no parts moved in this pass

there are 389 unrouted connections left, down from 480. all 554 connection checks passed and there are no new DRC findings. 74 old dangling-via and silkscreen warnings remain. next is the rest of the sensing, brake control and peripheral wiring. still plenty to finish before this board can be ordered

safety-overview

supervisor-detail

### 2026-10-08 – Devlog 12: current feedback and references

**1h**

Devlog 12: current feedback and references

connected the three current amplifier outputs to their filters, the stm32 and the hardware current comparators. the diagnostic filter outputs now reach the ADC too. the gate driver's three diagnostic output connections still need their own fanout pass

finished the 2.5V reference and 1.25V bias wiring, plus the supply feeds for the current amplifiers. connected the overcurrent and bus-status sense lines back to the MCU

the reference and ground fanouts at the stm32 were blocking each other. rerouted those two short connections, then moved the Hall 3 via farther out to make room for the bus-status trace. the part positions and values stayed the same

the new traces split a few pieces of the ground and 3V3 pours. added direct connections, fixed the ground thermals and put ground stitches near the layer changes. removed the unused vias and trace stubs from the earlier route attempts

all 731 connection checks pass, with no new DRC findings or schematic mismatches. there are 349 unrouted connections left, down from 389, and 62 existing via and silkscreen warnings. next are the driver diagnostic connections, then the remaining sensing and brake control. nothing has been built or powered yet

current-overview

reference

### 2026-10-08 – Devlog 13: driver current sensing

**1h**

Devlog 13: driver current sensing

finished the drv8353 current sensing connections. SOA, SOB and SOC now reach their filter resistors and adc inputs, and the three negative sense inputs go back to the shunts.

this corner of the board was really tight. i redid the pin exits and a few supply and safety traces to get everything through. i also removed an unused reference supply branch and added some ground stitching. all the components stayed in place.

after refilling the copper, a few small 3v3 areas had become disconnected, so i joined them with traces. the connection checks pass and there are no new drc issues. 343 connections left to route, down from 349.

driver-routing

current-diagnostics

### 2026-10-09 – Devlog 14: voltage and temperature sensing

**1h**

Devlog 14: voltage and temperature sensing

routed the bus and three phase voltage dividers, their buffers and the filters at the stm32. the phase pickups connect to the existing power copper. also connected the 3v3 monitor and USB voltage detection.

finished the bridge, board, motor and brake temperature signals. connected the sensor pull-ups, reference feeds, buffer supplies and ground returns too. the analog input and feedback connections stay local around the amplifiers.

the MCU corner was tight again. rerouted a few control traces and removed some unfinished fanout stubs to get the sensor connections through. none of the parts moved. after refilling the pours, i joined the ground and 3v3 areas that had been cut off and added ground stitches near the layer changes.

the connection checks pass, with no new drc findings or schematic mismatches. there are 264 connections left to route, down from 343. 51 old via and silkscreen warnings remain.

next are the remaining brake controls and power branches, then the interfaces. still a PCB design, nothing built or powered yet.

voltage-sensing

temperature-sensing

### 2026-10-09 – Devlog 15: brake controls and power branches

**1h**

Devlog 15: brake controls and power branches

connected the brake voltage divider, hysteresis circuit and reference supply. routed the current comparator, power-on delay and safety latch too. the brake current output now reaches the comparator and test point, and the fault-status divider reaches the stm32.

finished the remaining 5v bus branches and connected the main bus bleed resistor, voltage pickup and test point. the upper USB ground pads were boxed in by an existing power trace, so i rerouted that short section and added a ground via.

two connections still need more work at the MCU: brake-active status and the brake-current ADC. their local dividers and filter are connected, but the existing fanout is too tight for the last links. kept the original MCU fanouts and reference route in place for this checkpoint.

refilled the copper, reconnected the supply areas split by the new traces, and added ground stitches near the layer changes. all the connection checks pass, with no new drc findings or schematic mismatches. ground is now one connected group. there are 205 connections left to route, down from 264, and 50 existing via and silkscreen warnings.

next is the MCU fanout and remaining interfaces. nothing has been built or powered yet.

brake-controls

brake-overview

### 2026-10-09 – Devlog 16: brake-active status

**2h**

Devlog 16: brake-active status

connected the brake-active divider to the stm32. the crowded part was the MCU escape, where the existing temperature-sense via left no room for the new trace. moved that via slightly and replaced its short connections to make space.

the new route split two small ground areas, so i added connections around C883 and R321. added a ground stitch near the brake-divider layer change and removed two old vias that were no longer connecting between layers.

the brake-current ADC still needs work. tried a wider fanout rebuild, but it broke existing reference and current-sense connections, so i kept that trial out of the saved board. the original ADC filter and MCU escape are still in place.

refilled the copper and checked the saved result. all 1247 connection checks pass, the earlier connected groups are preserved, and there are no new drc findings or schematic mismatches. 204 connections remain, down from 205. there are 49 existing via and silkscreen warnings.

next is the brake-current ADC escape and the remaining interfaces. the board hasn't been built or powered yet.

brake-active-route

brake-active-mcu

### 2026-10-09 – Devlog 17: Hall, encoder and brake-current inputs

**1h**

Devlog 17: Hall, encoder and brake-current inputs

finished the brake-current ADC connection, then routed the Hall and encoder interfaces. all six channels now run from the connectors through the protection and filter parts, through the buffers and into the stm32.

connected the separate switched 5v feeds for the Hall sensors and encoder, including the current-limit resistors and bypass capacitors. the MCU can enable each supply and read its fault output. connected the buffer supplies, pull-ups and the other branches sharing the Hall supply too.

the MCU escapes needed more work. rebuilt the unused pin exits and rerouted a few nearby control and temperature-sense traces to make room. kept the part positions, values and pin assignments the same. every displaced connection is restored.

after refilling the copper, reconnected the ground and 3v3 areas that the new traces had split. cleaned up the old trace stubs, fixed the incomplete thermals and added ground stitches near the layer changes.

all 1492 connection checks pass, with no new drc findings or schematic mismatches. there are 134 connections left to route, down from 204 at the last devlog. 41 existing via and silkscreen warnings remain.

next are the throttle and digital control inputs, then the remaining communications. nothing has been built or powered yet.

adc-route

sensor-inputs

sensor-mcu

### 2026-10-10 – Devlog 18: throttle and control inputs

**1h**

Devlog 18: throttle and control inputs

finished the throttle and auxiliary analog inputs. connected their protection, voltage dividers, clamps and op-amp buffers, then routed the ADC filters and the last connections to the stm32.

routed the RC PWM, brake and direction channels through their protection and Schmitt buffers. connected the pull-ups, pull-downs, local supplies and ground returns too.

the MCU corner was tight again. rebuilt the brake and direction pin escapes and rerouted a few nearby voltage, status and Hall/encoder traces to get through. all the affected connections are restored, with the parts and pin assignments unchanged.

refilled the copper, reconnected the ground areas and cleaned up the unused trace ends. checked older signal returns near the new routing too. added a short bottom-layer ground trace to restore an existing stitch under the MCU.

all 1626 connection checks pass, with no new drc findings or schematic mismatches. there are 88 connections left to route, down from 134. 36 existing via and silkscreen warnings remain.

next are the communications and programming connections. nothing has been built or powered yet.

control-inputs

control-mcu

### 2026-10-10 – Devlog 19: boot controls and local wiring

**1h**

Devlog 19: boot controls and local wiring

connected the boot jumper and user button to the stm32, including the pull-up and both button pads. wired the LED resistor branches and the local EEPROM data and write-protect connections too.

joined more of the 3v3 branches, including the MCU backup supply, debug connector, CAN chip and its bypass capacitors. connected the CAN transmit and standby pull-ups. three supply pads around the EEPROM still need connecting.

tried a larger communications routing pass, but it kept disturbing finished MCU connections. kept that trial out of the saved board and finished the local wiring first. none of the earlier tracks or vias moved.

refilled the copper, reconnected the small ground areas and added three ground stitches near the layer changes. all 1678 connection checks pass, with no new drc findings or schematic mismatches. 62 connections left, down from 88. 34 existing via and silkscreen warnings remain.

next is a closer look at the MCU exits for programming and communications. the board has not been built or powered yet.

local-controls

local-supplies

### 2026-10-10 – Devlog 20: CAN bus wiring

**0.25h**

Devlog 20: CAN bus wiring

routed CAN high and low from the connector through the protection chip to the transceiver. rotated the protection chip so the traces pass through its pads on the way into the board. connected the 120 ohm termination resistor and its jumper too.

added short ground returns at the protection chip and more plane connections beside the CAN chip and its bypass capacitors. both bus lines use two vias, with ground stitches near the layer changes.

the first check caught a crossing with a temperature-sense trace and a via too close to an inner-layer signal. moved the new wiring around them. the existing tracks and vias stayed in place. also reconnected a small ground area near C886 after refilling the copper.

all 1705 connection checks pass, with no new drc findings or schematic mismatches. 55 connections left, down from 62. the 34 existing via and silkscreen warnings are unchanged.

the three CAN logic connections to the stm32 still need routing, along with the other remaining interfaces. nothing has been built or powered yet.

can-bus

can-protection

### 2026-10-10 – Devlog 21: bridge test points and snubbers

**0.5h**

Devlog 21: bridge test points and snubbers

connected the gate, source and phase test points around the bridge. several were far from the nodes they measured, so moved them closer before routing. all twelve are connected now. the existing gate-drive and power traces stayed where they were.

finished the three optional snubber branches too. kept their values and do-not-populate settings the same. these still need tuning from measurements on a real board.

made a local version of the test-point footprint with the same pad and courtyard, but without the front silkscreen ring. put the probe labels on the back to clear the crowded MOSFET markings, and updated the schematic footprint assignments to match.

all 1723 connection checks pass, with no new drc findings or schematic mismatches. erc is clean too. checked the filled power copper separately and none of the existing bus, phase or source copper was lost. 38 connections left, down from 55. 32 existing via and silkscreen warnings remain.

next are the remaining clock, programming and communication connections. the board has not been built or powered yet.

bridge-probes

phase-b-probes

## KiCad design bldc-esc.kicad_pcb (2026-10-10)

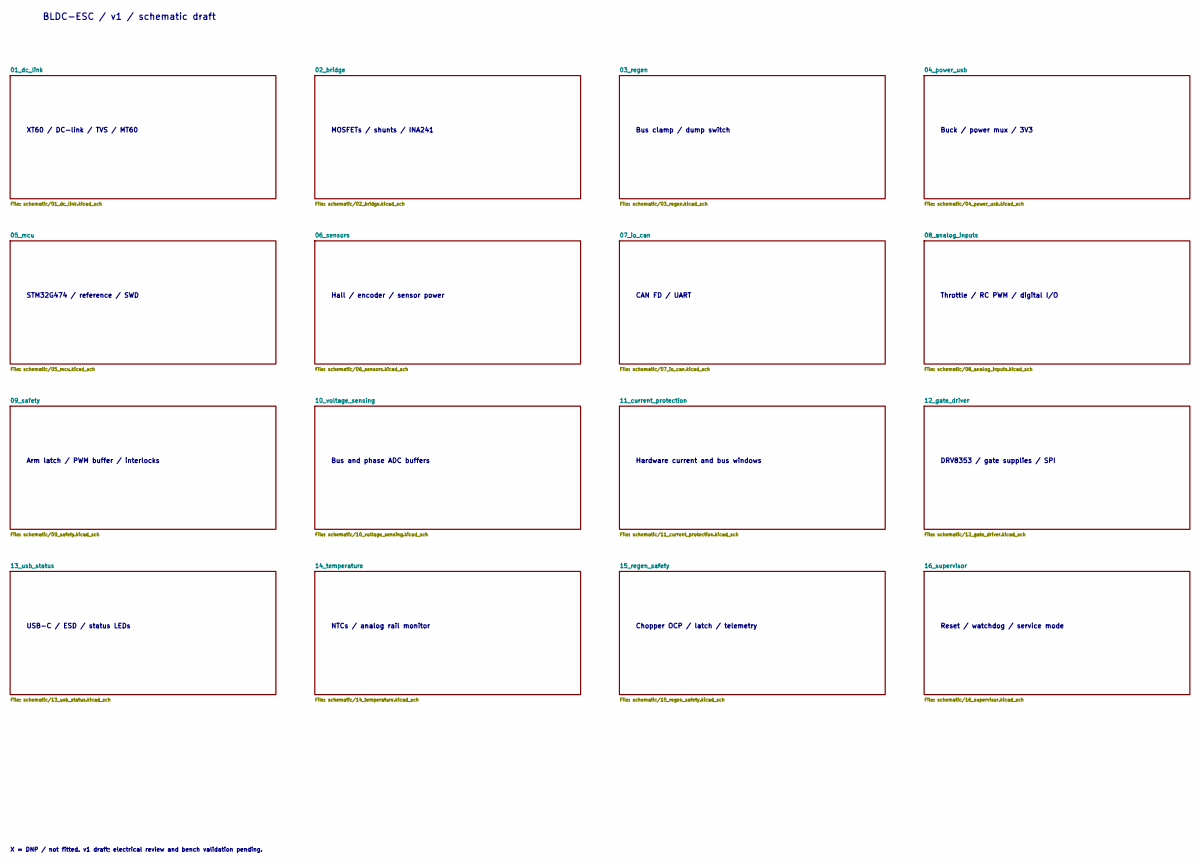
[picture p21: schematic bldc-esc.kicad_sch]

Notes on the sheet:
BLDC-ESC / v1 / schematic draft
XT60 / DC-link / TVS / MT60
MOSFETs / shunts / INA241
Bus clamp / dump switch
Buck / power mux / 3V3
STM32G474 / reference / SWD
Hall / encoder / sensor power
CAN FD / UART
Throttle / RC PWM / digital I/O
Arm latch / PWM buffer / interlocks
Bus and phase ADC buffers
Hardware current and bus windows
DRV8353 / gate supplies / SPI
USB-C / ESD / status LEDs
NTCs / analog rail monitor
Chopper OCP / latch / telemetry
Reset / watchdog / service mode
X = DNP / not fitted. v1 draft; electrical review and bench validation pending.

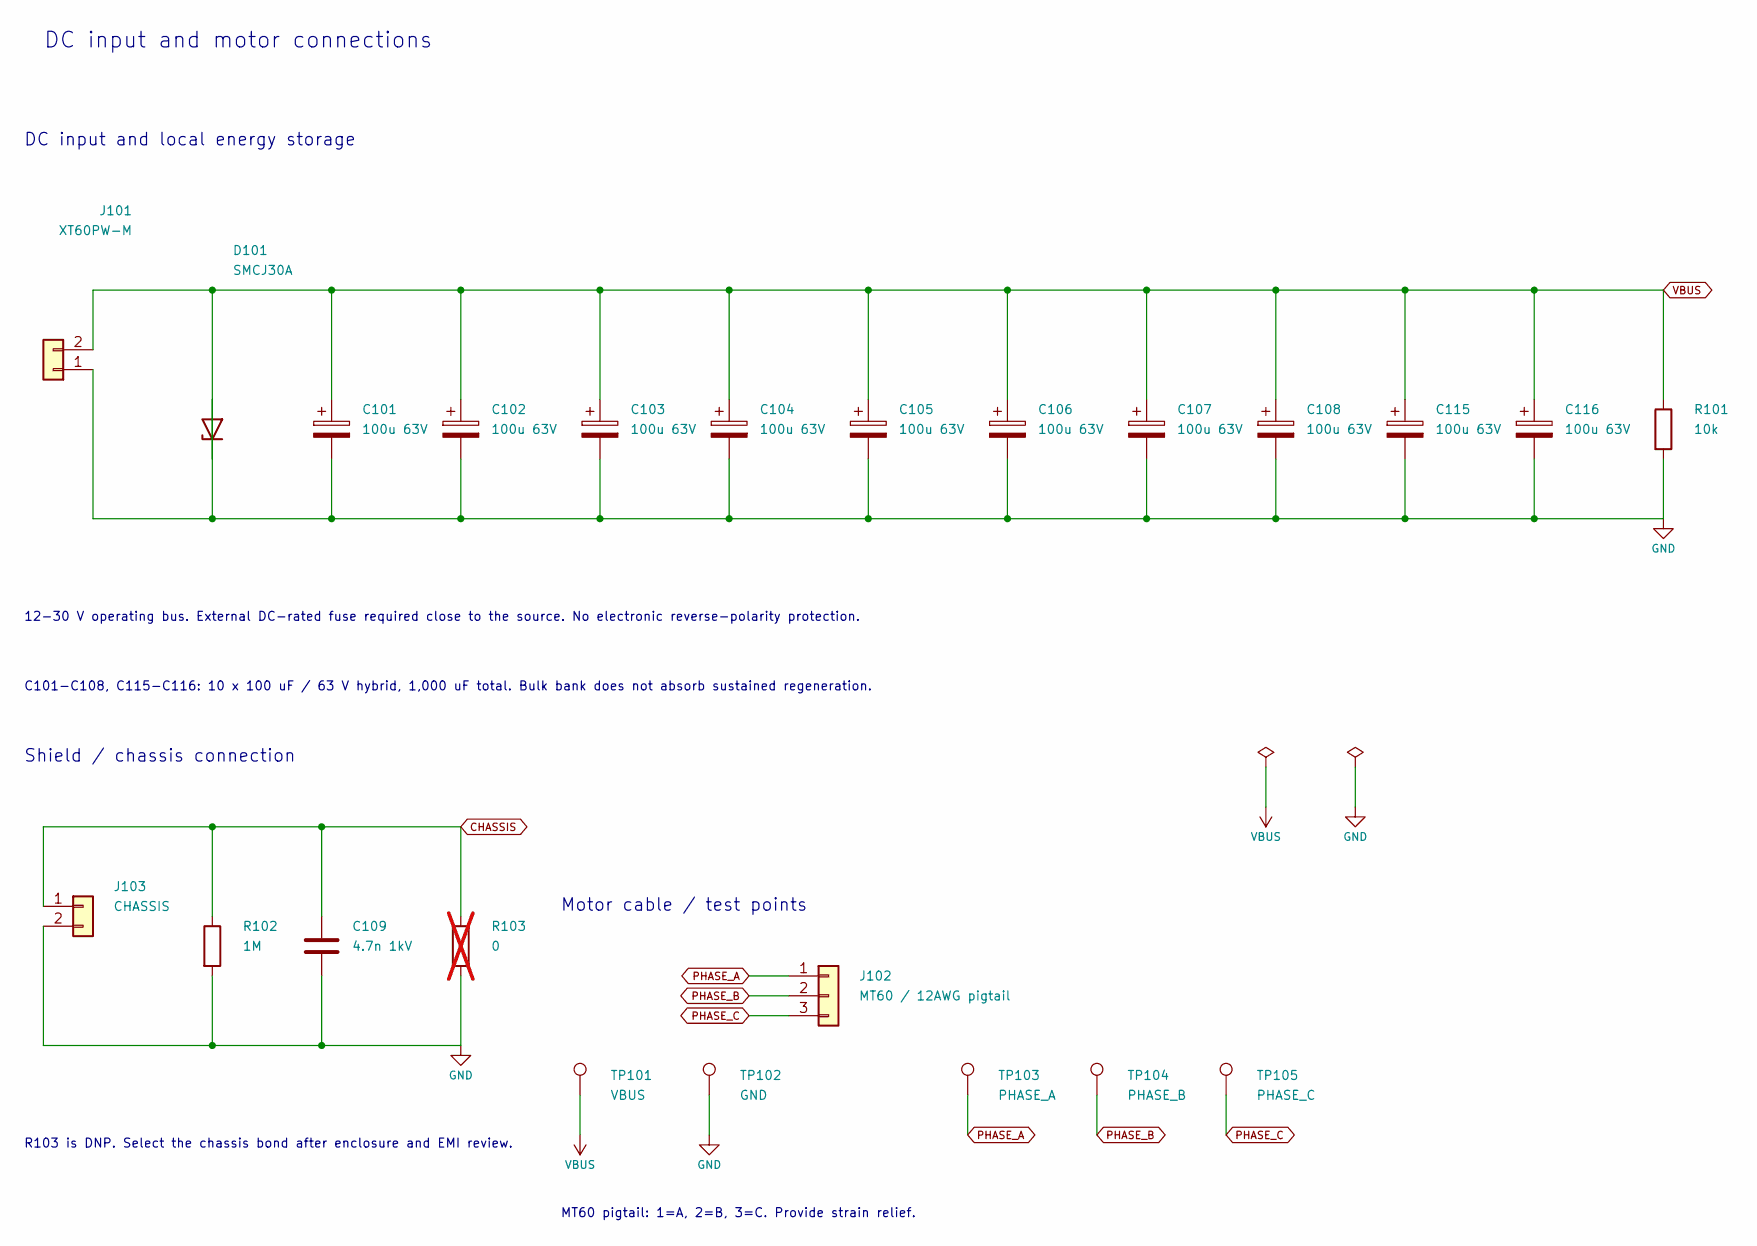
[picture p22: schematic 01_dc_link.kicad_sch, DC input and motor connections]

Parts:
C101, C102, C103, C104, C105, C106, C107, C108, C115, C116: 100u 63V; CP_Elec_10x12.5; MPN GXC1J101MCW1GS
C109: 4.7n 1kV; C_1206_3216Metric; MPN C1206C472KDRACTU
D101: SMCJ30A; D_SMC; MPN SMCJ30A
J101: XT60PW-M; AMASS_XT60PW-M_1x02_P7.20mm_Horizontal; MPN XT60PW-M
J102: MT60 / 12AWG pigtail; MT60_Pigtail_12AWG; MPN MT60-M
J103: CHASSIS; PinHeader_1x02_P2.54mm_Vertical; MPN M20-9990245
R101: 10k; R_1206_3216Metric; MPN RC1206FR-0710KL
R102: 1M; R_0603_1608Metric; MPN RC0603FR-071ML
R103: 0; R_0603_1608Metric; MPN RC0603JR-070RL; not fitted
TP101: VBUS; TestPoint_Pad_D1.5mm; MPN TESTPOINT
TP102: GND; TestPoint_Pad_D1.5mm; MPN TESTPOINT
TP103: PHASE_A; TestPoint_Pad_D1.5mm_NoSilk; MPN TESTPOINT
TP104: PHASE_B; TestPoint_Pad_D1.5mm_NoSilk; MPN TESTPOINT
TP105: PHASE_C; TestPoint_Pad_D1.5mm_NoSilk; MPN TESTPOINT

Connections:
CHASSIS: C109.1, J103.1, R102.1, R103.1; also elsewhere on the board
PHASE_A: J102.1, TP103.1 (1_1); also elsewhere on the board
PHASE_B: J102.2, TP104.1 (1_1); also elsewhere on the board
PHASE_C: J102.3, TP105.1 (1_1); also elsewhere on the board
VBUS: C101.1, C102.1, C103.1, C104.1, C105.1, C106.1, C107.1, C108.1, C115.1, C116.1, D101.1 (K), J101.2, R101.1, TP101.1 (1_1); also elsewhere on the board

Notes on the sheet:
DC input and motor connections
DC input and local energy storage
12-30 V operating bus. External DC-rated fuse required close to the source. No electronic reverse-polarity protection.
C101-C108, C115-C116: 10 x 100 uF / 63 V hybrid, 1,000 uF total. Bulk bank does not absorb sustained regeneration.
Shield / chassis connection
R103 is DNP. Select the chassis bond after enclosure and EMI review.
Motor cable / test points
MT60 pigtail: 1=A, 2=B, 3=C. Provide strain relief.

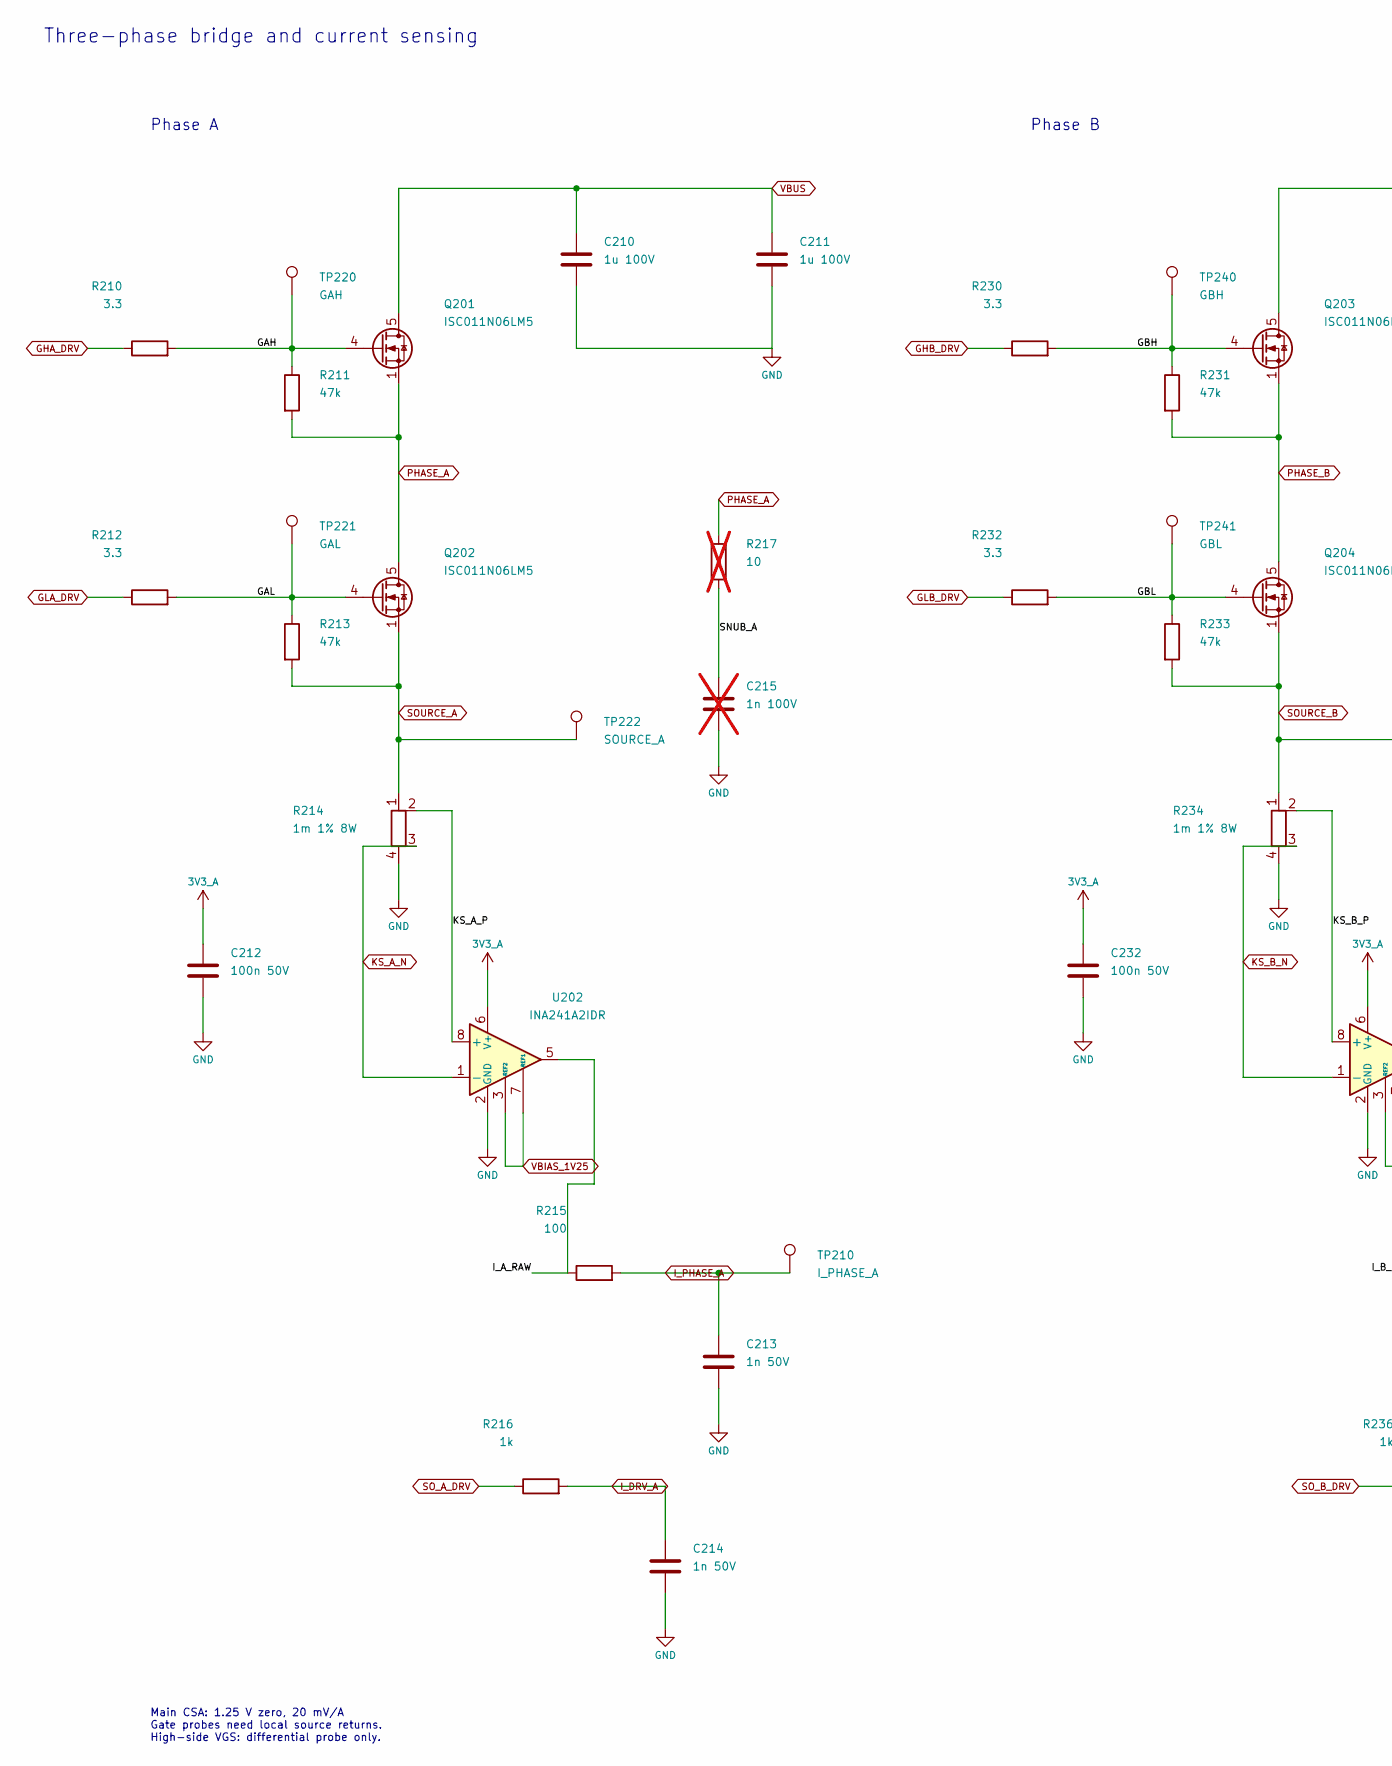
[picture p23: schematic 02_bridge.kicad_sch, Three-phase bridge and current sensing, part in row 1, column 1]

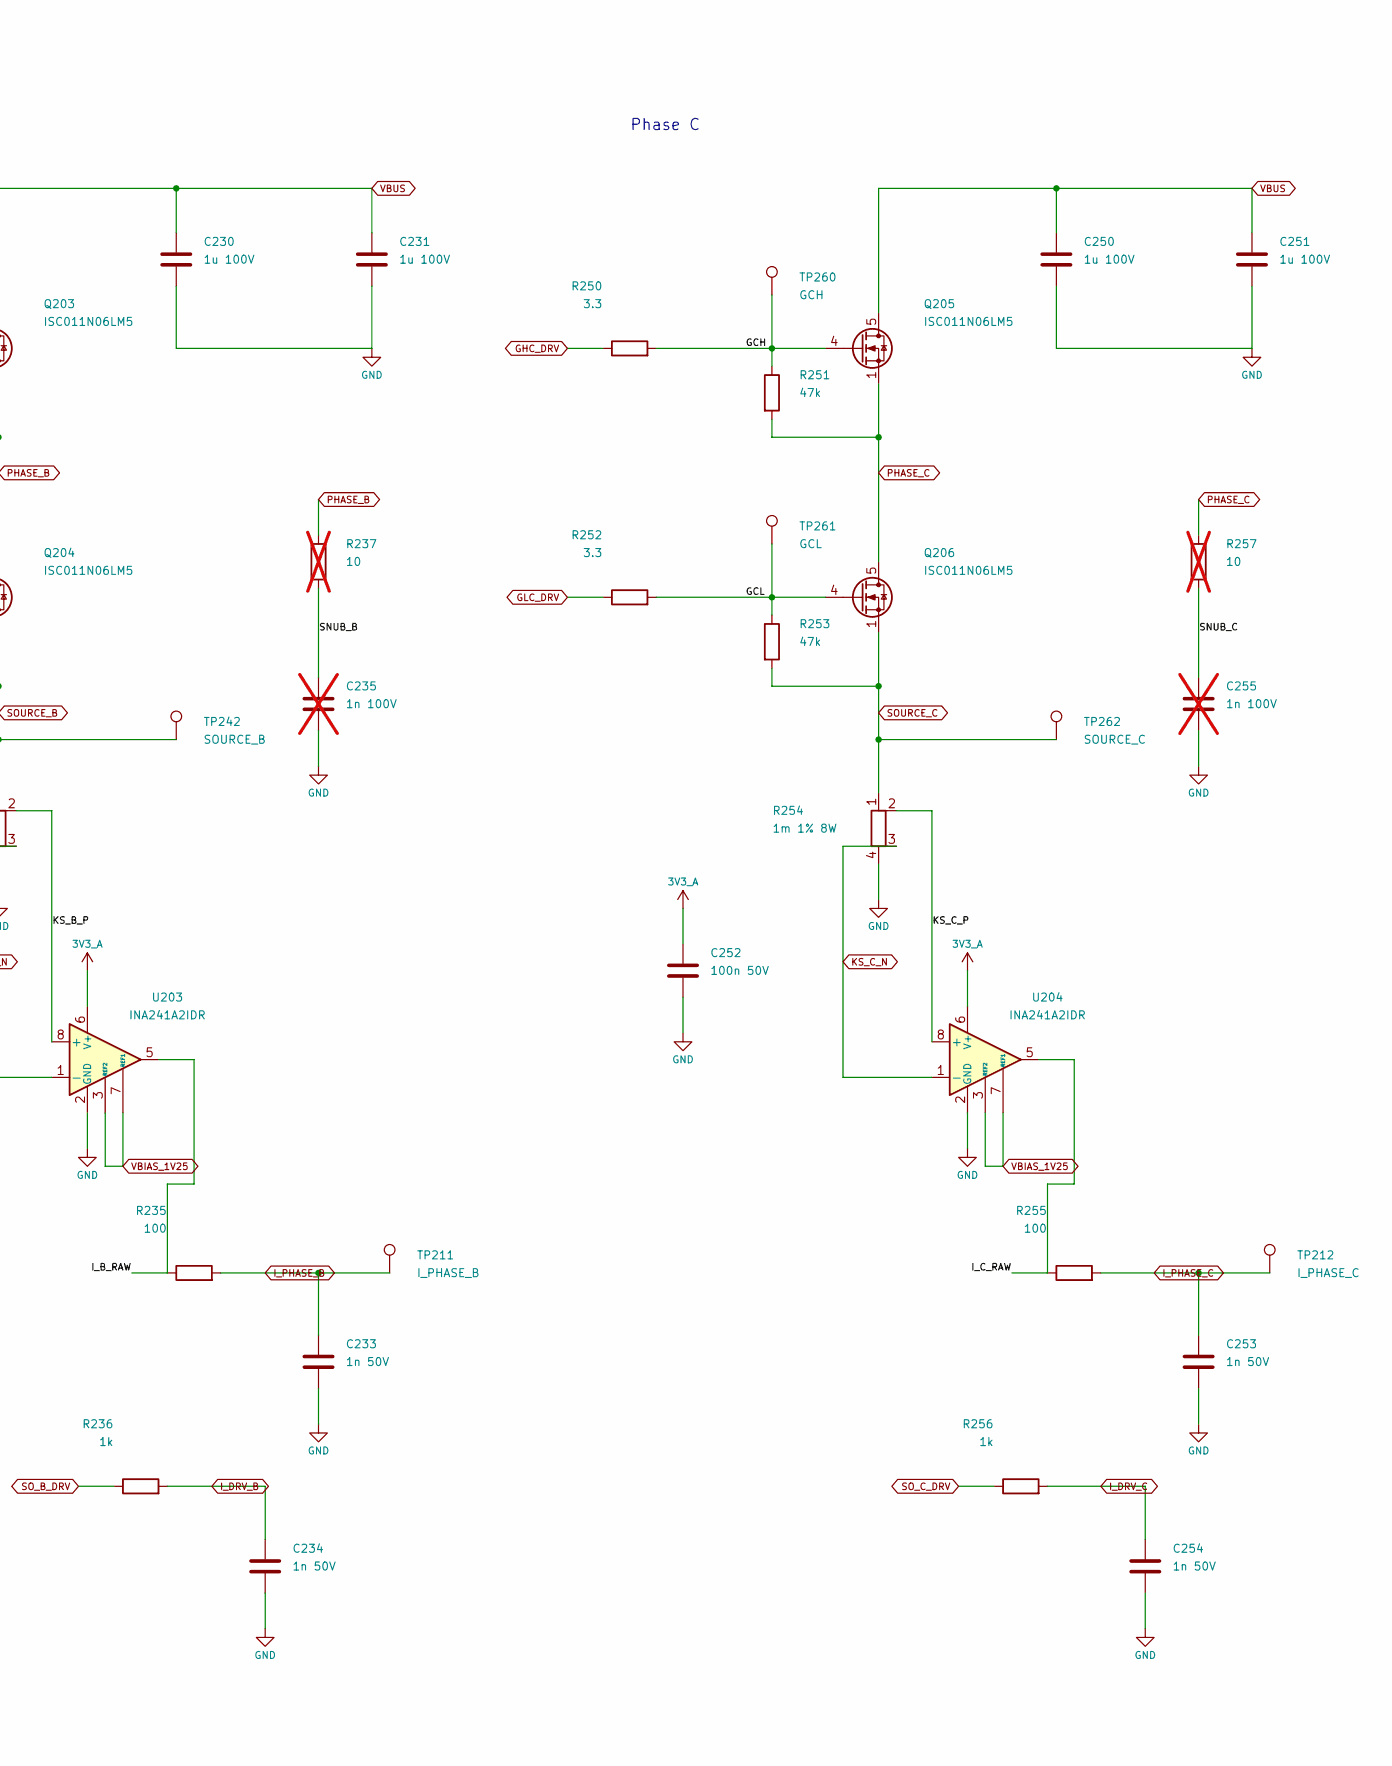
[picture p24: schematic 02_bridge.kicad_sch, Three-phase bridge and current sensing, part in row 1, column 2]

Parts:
C210, C211, C230, C231, C250, C251: 1u 100V; C_1206_3216Metric; MPN C3216X7R2A105K160AA
C212, C232, C252: 100n 50V; C_0603_1608Metric; MPN C0603C104K5RACTU
C213, C214, C233, C234, C253, C254: 1n 50V; C_0603_1608Metric; MPN C0603C102J5GACTU
C215, C235, C255: 1n 100V; C_0805_2012Metric; MPN C0805C102J1GACTU; not fitted
Q201, Q202, Q203, Q204, Q205, Q206: ISC011N06LM5; Infineon_PG-TDSON-8_6.15x5.15mm; MPN ISC011N06LM5ATMA1
R210, R212, R230, R232, R250, R252: 3.3; R_0603_1608Metric; MPN RC0603FR-073R3L
R211, R213, R231, R233, R251, R253: 47k; R_0603_1608Metric; MPN RC0603FR-0747KL
R214, R234, R254: 1m 1% 8W; CSS4J_4026; MPN CSS4J-4026R-1L00F
R215, R235, R255: 100; R_0603_1608Metric; MPN RC0603FR-07100RL
R216, R236, R256: 1k; R_0603_1608Metric; MPN RC0603FR-071KL
R217, R237, R257: 10; R_0805_2012Metric; MPN RC0805FR-0710RL; not fitted
TP210: I_PHASE_A; TestPoint_Pad_D1.5mm; MPN TESTPOINT
TP211: I_PHASE_B; TestPoint_Pad_D1.5mm; MPN TESTPOINT
TP212: I_PHASE_C; TestPoint_Pad_D1.5mm; MPN TESTPOINT
TP220: GAH; TestPoint_Pad_D1.5mm_NoSilk; MPN TESTPOINT
TP221: GAL; TestPoint_Pad_D1.5mm_NoSilk; MPN TESTPOINT
TP222: SOURCE_A; TestPoint_Pad_D1.5mm_NoSilk; MPN TESTPOINT
TP240: GBH; TestPoint_Pad_D1.5mm_NoSilk; MPN TESTPOINT
TP241: GBL; TestPoint_Pad_D1.5mm_NoSilk; MPN TESTPOINT
TP242: SOURCE_B; TestPoint_Pad_D1.5mm_NoSilk; MPN TESTPOINT
TP260: GCH; TestPoint_Pad_D1.5mm_NoSilk; MPN TESTPOINT
TP261: GCL; TestPoint_Pad_D1.5mm_NoSilk; MPN TESTPOINT
TP262: SOURCE_C; TestPoint_Pad_D1.5mm_NoSilk; MPN TESTPOINT
U202, U203, U204: INA241A2IDR; SOIC-8_3.9x4.9mm_P1.27mm; MPN INA241A2IDR

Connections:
3V3_A: C212.1, C232.1, C252.1, U202.6 (V+), U203.6 (V+), U204.6 (V+); also elsewhere on the board
/02_bridge/GAH: Q201.4 (G), R210.2, R211.1, TP220.1 (1_1)
/02_bridge/GAL: Q202.4 (G), R212.2, R213.1, TP221.1 (1_1)
/02_bridge/GBH: Q203.4 (G), R230.2, R231.1, TP240.1 (1_1)
/02_bridge/GBL: Q204.4 (G), R232.2, R233.1, TP241.1 (1_1)
/02_bridge/GCH: Q205.4 (G), R250.2, R251.1, TP260.1 (1_1)
/02_bridge/GCL: Q206.4 (G), R252.2, R253.1, TP261.1 (1_1)
/02_bridge/I_A_RAW: R215.1, U202.5
/02_bridge/I_B_RAW: R235.1, U203.5
/02_bridge/I_C_RAW: R255.1, U204.5
/02_bridge/KS_A_P: R214.2, U202.8 (+)
/02_bridge/KS_B_P: R234.2, U203.8 (+)
/02_bridge/KS_C_P: R254.2, U204.8 (+)
/02_bridge/SNUB_A: C215.1, R217.2
/02_bridge/SNUB_B: C235.1, R237.2
/02_bridge/SNUB_C: C255.1, R257.2
GHA_DRV: R210.1; also elsewhere on the board
GHB_DRV: R230.1; also elsewhere on the board
GHC_DRV: R250.1; also elsewhere on the board
GLA_DRV: R212.1; also elsewhere on the board
GLB_DRV: R232.1; also elsewhere on the board
GLC_DRV: R252.1; also elsewhere on the board
I_DRV_A: C214.1, R216.2; also elsewhere on the board
I_DRV_B: C234.1, R236.2; also elsewhere on the board
I_DRV_C: C254.1, R256.2; also elsewhere on the board
I_PHASE_A: C213.1, R215.2, TP210.1 (1_1); also elsewhere on the board
I_PHASE_B: C233.1, R235.2, TP211.1 (1_1); also elsewhere on the board
I_PHASE_C: C253.1, R255.2, TP212.1 (1_1); also elsewhere on the board
KS_A_N: R214.3, U202.1 (-); also elsewhere on the board
KS_B_N: R234.3, U203.1 (-); also elsewhere on the board
KS_C_N: R254.3, U204.1 (-); also elsewhere on the board
PHASE_A: Q201.1 (S), Q201.2 (S), Q201.3 (S), Q202.5 (D), R211.2, R217.1; also elsewhere on the board
PHASE_B: Q203.1 (S), Q203.2 (S), Q203.3 (S), Q204.5 (D), R231.2, R237.1; also elsewhere on the board
PHASE_C: Q205.1 (S), Q205.2 (S), Q205.3 (S), Q206.5 (D), R251.2, R257.1; also elsewhere on the board
SOURCE_A: Q202.1 (S), Q202.2 (S), Q202.3 (S), R213.2, R214.1, TP222.1 (1_1); also elsewhere on the board
SOURCE_B: Q204.1 (S), Q204.2 (S), Q204.3 (S), R233.2, R234.1, TP242.1 (1_1); also elsewhere on the board
SOURCE_C: Q206.1 (S), Q206.2 (S), Q206.3 (S), R253.2, R254.1, TP262.1 (1_1); also elsewhere on the board
SO_A_DRV: R216.1; also elsewhere on the board
SO_B_DRV: R236.1; also elsewhere on the board
SO_C_DRV: R256.1; also elsewhere on the board
VBIAS_1V25: U202.3 (REF2), U202.7 (REF1), U203.3 (REF2), U203.7 (REF1), U204.3 (REF2), U204.7 (REF1); also elsewhere on the board
VBUS: C210.1, C211.1, C230.1, C231.1, C250.1, C251.1, Q201.5 (D), Q203.5 (D), Q205.5 (D); also elsewhere on the board

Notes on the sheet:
Three-phase bridge and current sensing
Phase A
Main CSA: 1.25 V zero, 20 mV/A Gate probes need local source returns. High-side VGS: differential probe only.
Phase B
Phase C

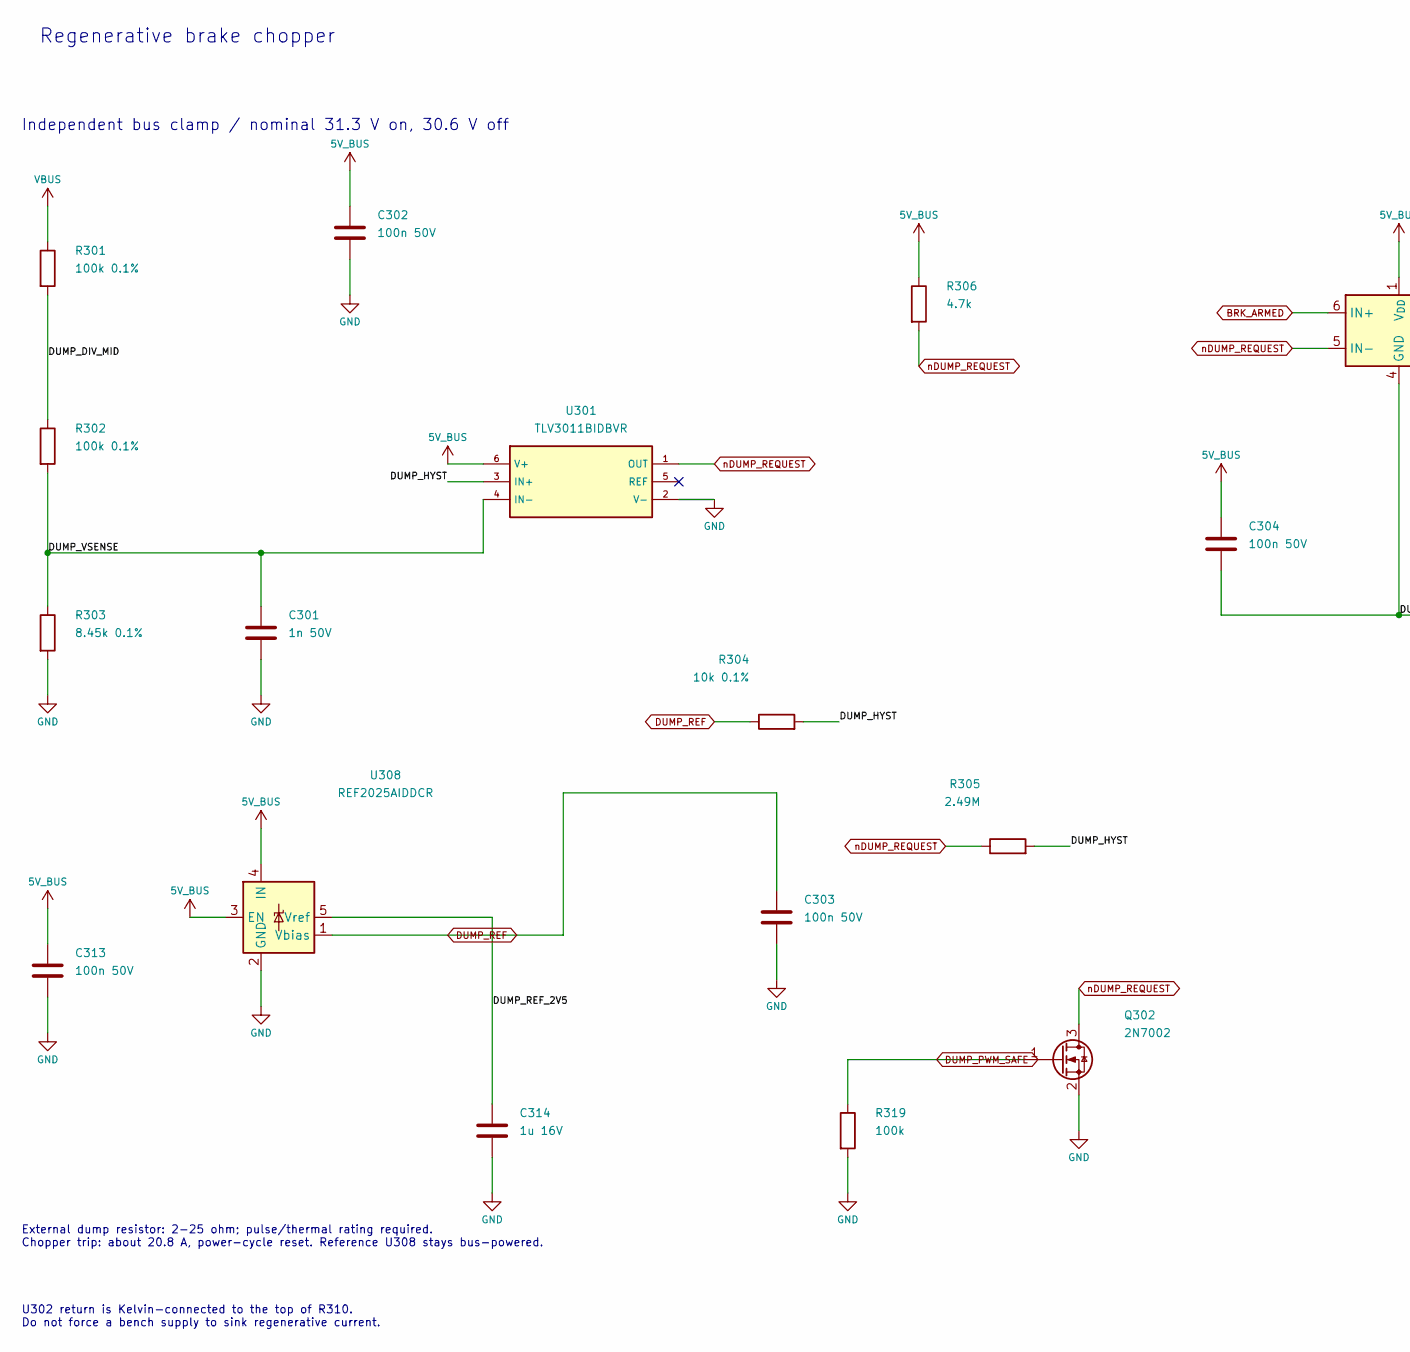
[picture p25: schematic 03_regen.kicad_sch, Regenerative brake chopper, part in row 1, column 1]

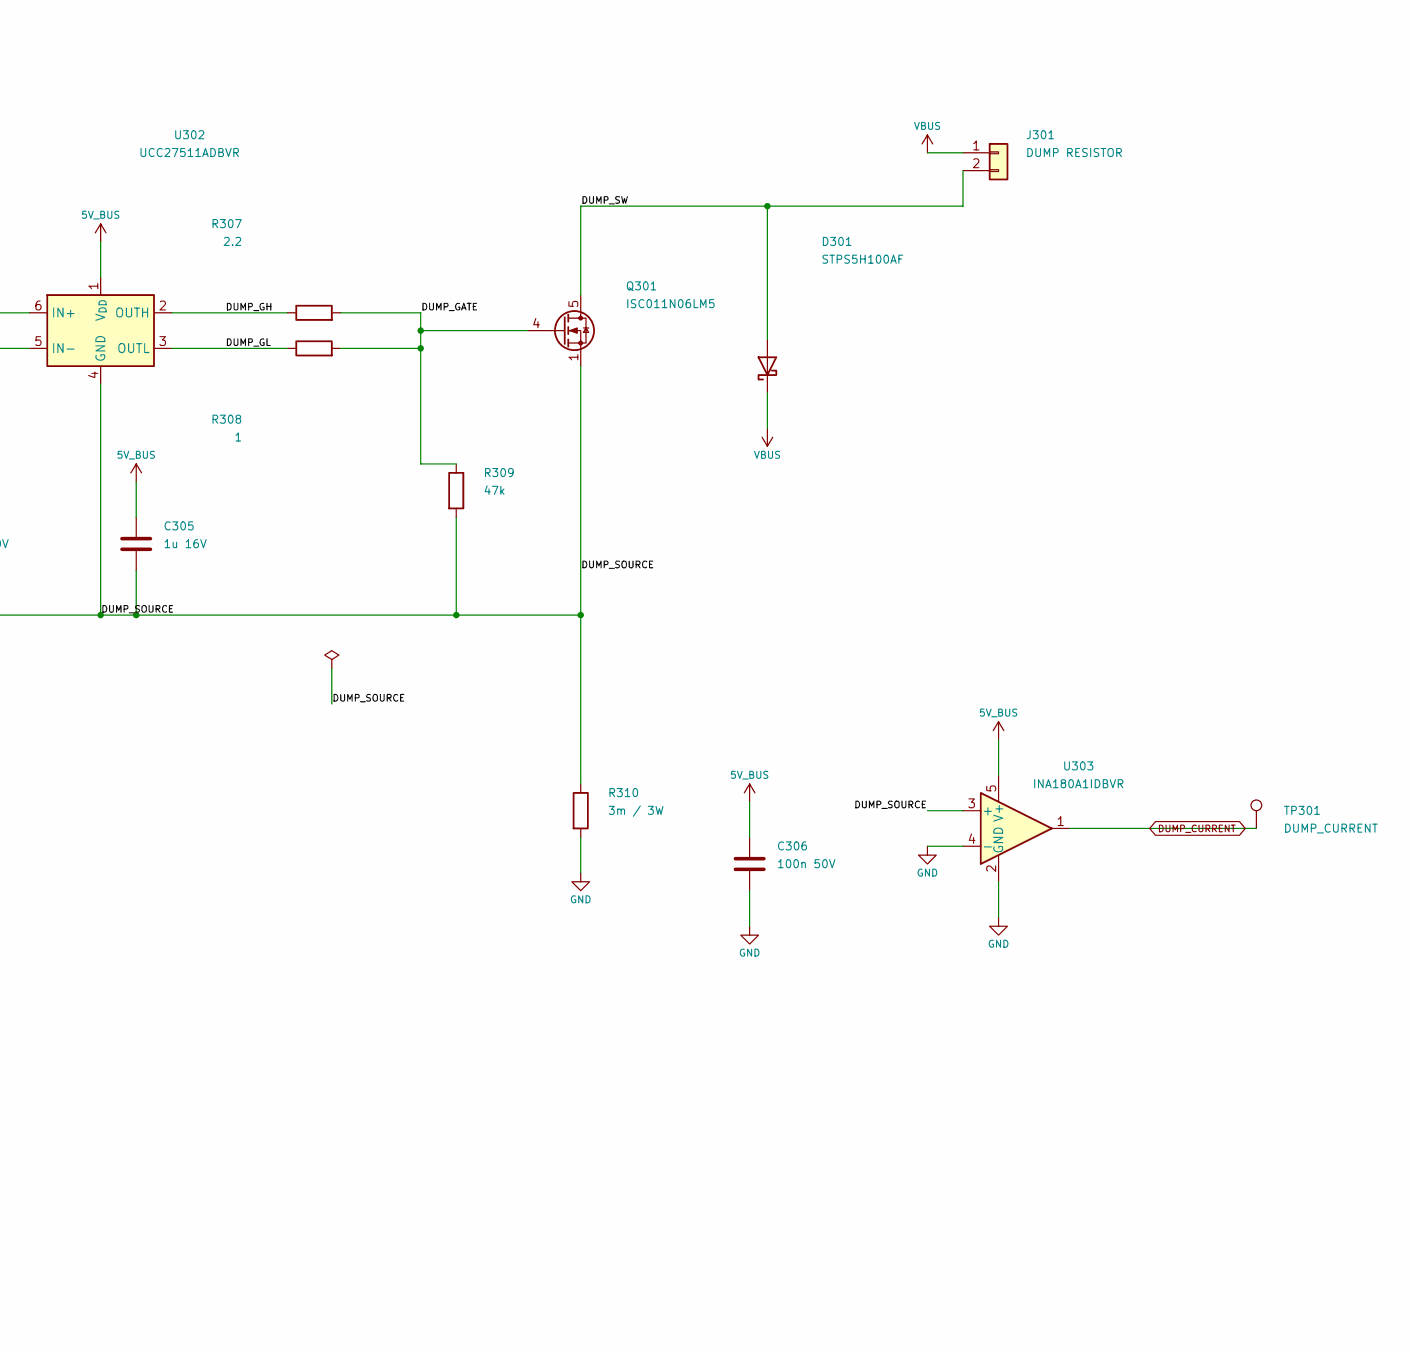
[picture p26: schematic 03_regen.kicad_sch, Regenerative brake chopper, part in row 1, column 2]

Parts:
C301: 1n 50V; C_0603_1608Metric; MPN C0603C102J5GACTU
C302, C303, C304, C306, C313: 100n 50V; C_0603_1608Metric; MPN C0603C104K5RACTU
C305, C314: 1u 16V; C_0603_1608Metric; MPN C0603C105K4RACTU
D301: STPS5H100AF; D_SOD-128; MPN STPS5H100AF
J301: DUMP RESISTOR; TerminalBlock_Phoenix_MKDS-3-2-5.08_1x02_P5.08mm_Horizontal; MPN 1711725
Q301: ISC011N06LM5; Infineon_PG-TDSON-8_6.15x5.15mm; MPN ISC011N06LM5ATMA1
Q302: 2N7002; SOT-23; MPN 2N7002P,215
R301, R302: 100k 0.1%; R_0603_1608Metric; MPN RT0603BRD07100KL
R303: 8.45k 0.1%; R_0603_1608Metric; MPN RT0603BRD078K45L
R304: 10k 0.1%; R_0603_1608Metric; MPN RT0603BRD0710KL
R305: 2.49M; R_0603_1608Metric; MPN RC0603FR-072M49L
R306: 4.7k; R_0603_1608Metric; MPN RC0603FR-074K7L
R307: 2.2; R_0603_1608Metric; MPN RC0603FR-072R2L
R308: 1; R_0603_1608Metric; MPN RC0603FR-071RL
R309: 47k; R_0603_1608Metric; MPN RC0603FR-0747KL
R310: 3m / 3W; R_2512_6332Metric; MPN WSLP2512R0030FEA
R319: 100k; R_0603_1608Metric; MPN RC0603FR-07100KL
TP301: DUMP_CURRENT; TestPoint_Pad_D1.5mm; MPN TESTPOINT
U301: TLV3011BIDBVR; SOT-23-6; MPN TLV3011BIDBVR
U302: UCC27511ADBVR; SOT-23-6; MPN UCC27511ADBVR
U303: INA180A1IDBVR; SOT-23-5; MPN INA180A1IDBVR
U308: REF2025AIDDCR; SOT-23-5; MPN REF2025AIDDCR

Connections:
5V_BUS: C302.1, C304.1, C305.1, C306.1, C313.1, R306.1, U301.6 (V+), U302.1 (V_{DD}), U303.5 (V+), U308.3 (EN), U308.4 (IN); also elsewhere on the board
/03_regen/DUMP_DIV_MID: R301.2, R302.1
/03_regen/DUMP_GATE: Q301.4 (G), R307.2, R308.2, R309.1
/03_regen/DUMP_GH: R307.1, U302.2 (OUTH)
/03_regen/DUMP_GL: R308.1, U302.3 (OUTL)
/03_regen/DUMP_HYST: R304.2, R305.2, U301.3 (IN+)
/03_regen/DUMP_REF_2V5: C314.1, U308.5 (Vref)
/03_regen/DUMP_SOURCE: C304.2, C305.2, Q301.1 (S), Q301.2 (S), Q301.3 (S), R309.2, R310.1, U302.4 (GND), U303.3 (+)
/03_regen/DUMP_SW: D301.2 (A), J301.2, Q301.5 (D)
/03_regen/DUMP_VSENSE: C301.1, R302.2, R303.1, U301.4 (IN-)
BRK_ARMED: U302.6 (IN+); also elsewhere on the board
DUMP_CURRENT: TP301.1 (1_1), U303.1; also elsewhere on the board
DUMP_PWM_SAFE: Q302.1 (G), R319.1; also elsewhere on the board
DUMP_REF: C303.1, R304.1, U308.1 (Vbias); also elsewhere on the board
VBUS: D301.1 (K), J301.1, R301.1; also elsewhere on the board
nDUMP_REQUEST: Q302.3 (D), R305.1, R306.2, U301.1 (OUT), U302.5 (IN-); also elsewhere on the board

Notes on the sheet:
Regenerative brake chopper
Independent bus clamp / nominal 31.3 V on, 30.6 V off
External dump resistor: 2-25 ohm; pulse/thermal rating required. Chopper trip: about 20.8 A, power-cycle reset. Reference U308 stays bus-powered.
U302 return is Kelvin-connected to the top of R310. Do not force a bench supply to sink regenerative current.

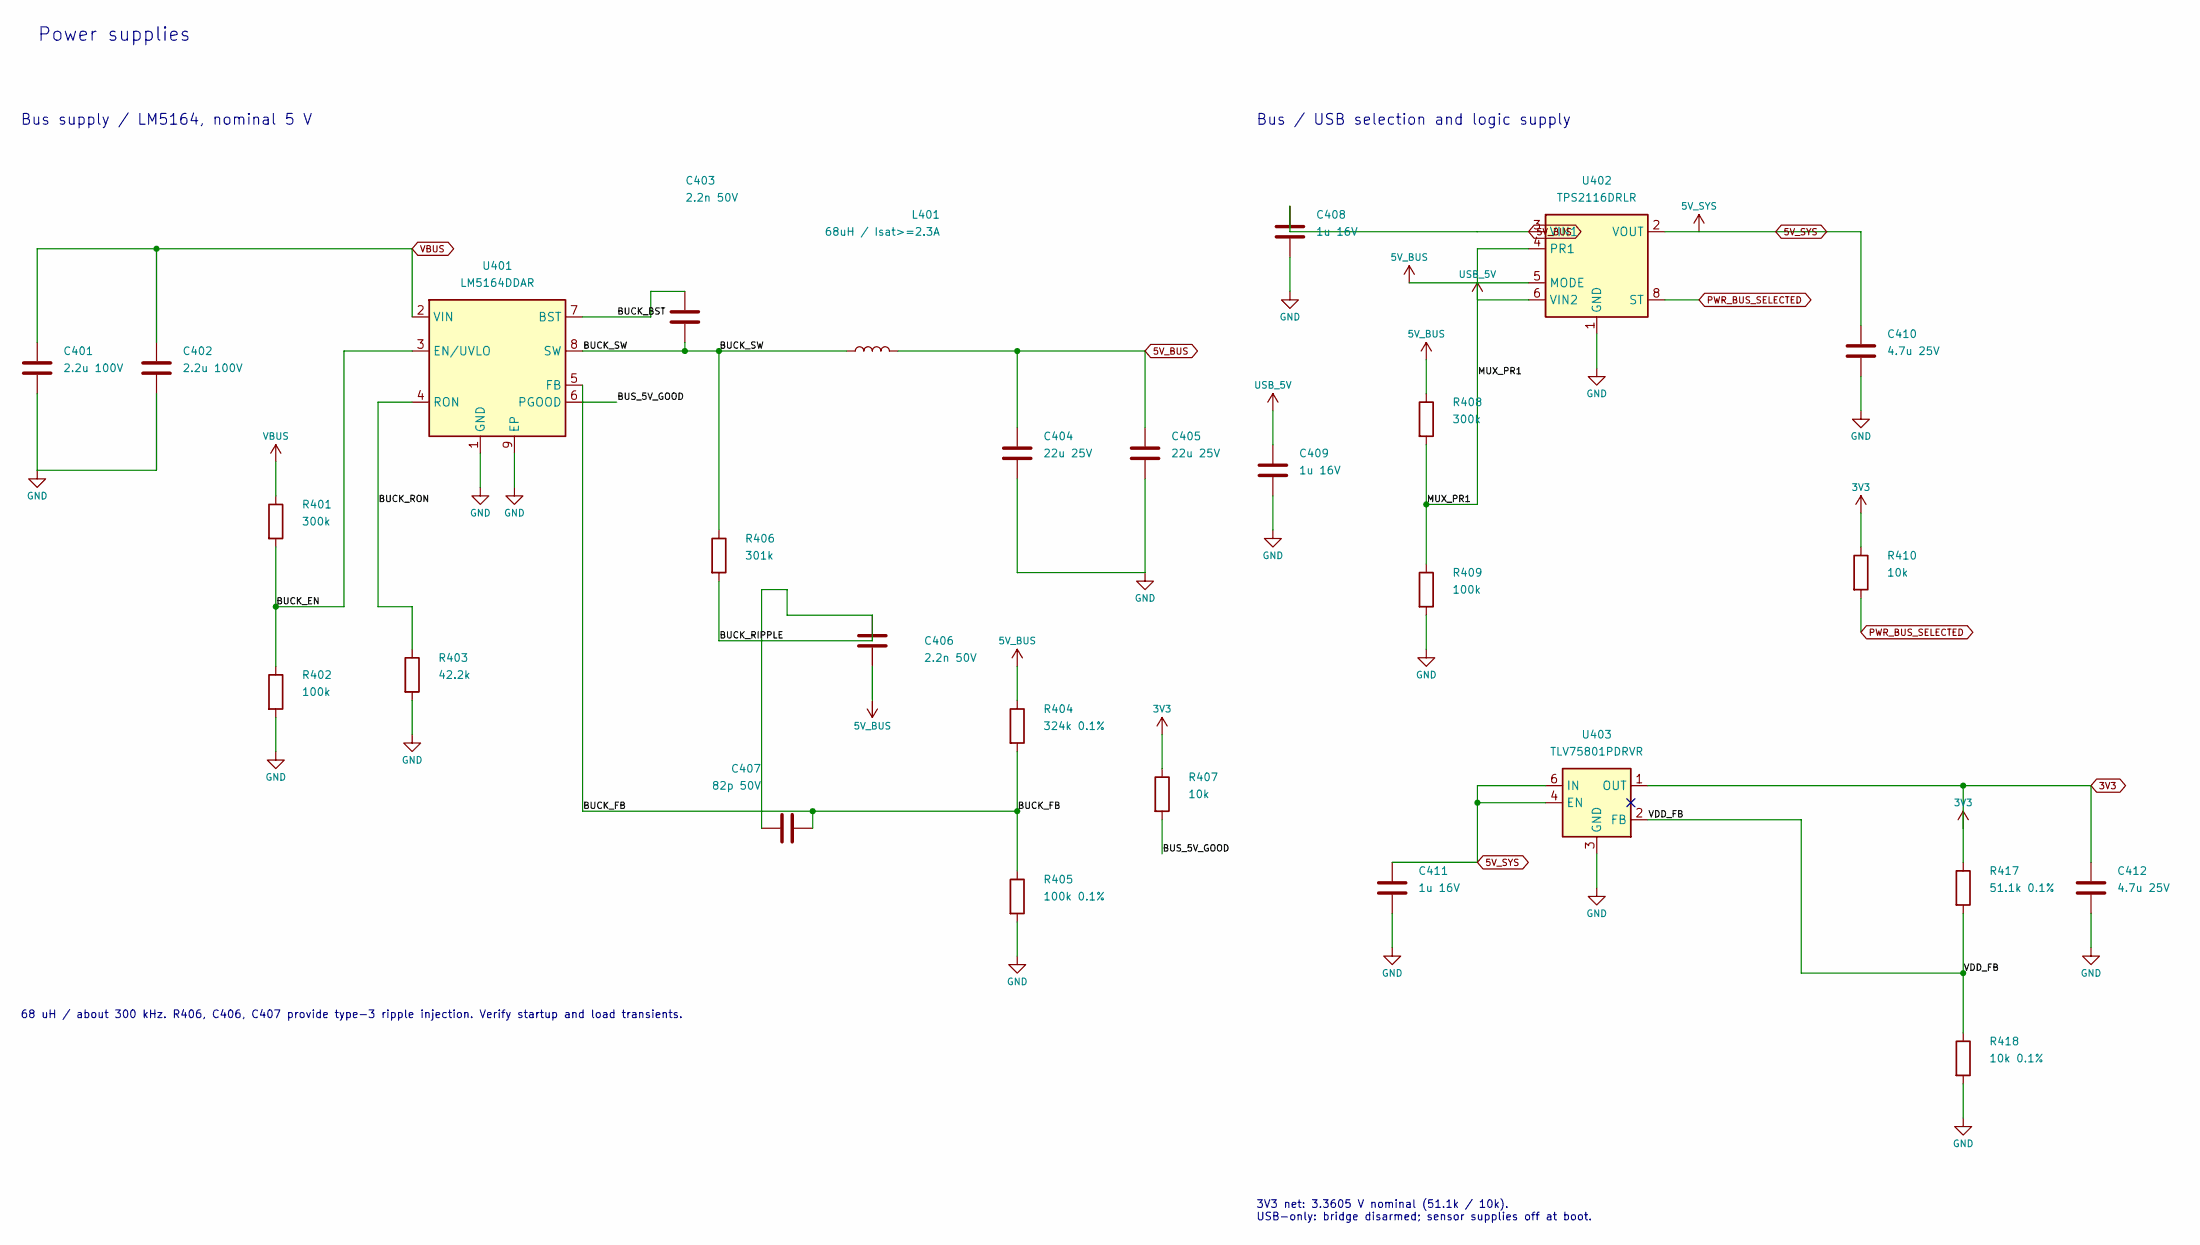
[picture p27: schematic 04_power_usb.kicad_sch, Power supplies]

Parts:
C401, C402: 2.2u 100V; C_1210_3225Metric; MPN CGA6N3X7R2A225K230AB
C403, C406: 2.2n 50V; C_0603_1608Metric; MPN C0603C222J5GACTU
C404, C405: 22u 25V; C_1210_3225Metric; MPN MSAST32MSB7226KPNB25
C407: 82p 50V; C_0603_1608Metric; MPN C0603C820J5GACTU
C408, C409, C411: 1u 16V; C_0603_1608Metric; MPN C0603C105K4RACTU
C410, C412: 4.7u 25V; C_0805_2012Metric; MPN C0805C475K3RACTU
L401: 68uH / Isat>=2.3A; L_Coilcraft_MSS1246T-XXX; MPN MSS1246T-683MLC
R401, R408: 300k; R_0603_1608Metric; MPN RC0603FR-07300KL
R402, R409: 100k; R_0603_1608Metric; MPN RC0603FR-07100KL
R403: 42.2k; R_0603_1608Metric; MPN RC0603FR-0742K2L
R404: 324k 0.1%; R_0603_1608Metric; MPN RT0603BRD07324KL
R405: 100k 0.1%; R_0603_1608Metric; MPN RT0603BRD07100KL
R406: 301k; R_0603_1608Metric; MPN RC0603FR-07301KL
R407, R410: 10k; R_0603_1608Metric; MPN RC0603FR-0710KL
R417: 51.1k 0.1%; R_0603_1608Metric; MPN RT0603BRD0751K1L
R418: 10k 0.1%; R_0603_1608Metric; MPN RT0603BRD0710KL
U401: LM5164DDAR; HSOP-8-1EP_3.9x4.9mm_P1.27mm_EP2.41x3.1mm_ThermalVias; MPN LM5164DDAR
U402: TPS2116DRLR; SOT-583-8; MPN TPS2116DRLR
U403: TLV75801PDRVR; WSON-6-1EP_2x2mm_P0.65mm_EP1x1.6mm; MPN TLV75801PDRVR

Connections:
3V3: C412.1, R407.1, R410.1, R417.1, U403.1 (OUT); also elsewhere on the board
5V_BUS: C404.1, C405.1, C406.2, C408.1, L401.2, R404.1, R408.1, U402.3 (VIN1), U402.5 (MODE); also elsewhere on the board
5V_SYS: C410.1, C411.1, U402.2 (VOUT), U402.7 (VOUT), U403.4 (EN), U403.6 (IN); also elsewhere on the board
/04_power_usb/BUCK_BST: C403.1, U401.7 (BST)
/04_power_usb/BUCK_EN: R401.2, R402.1, U401.3 (EN/UVLO)
/04_power_usb/BUCK_FB: C407.2, R404.2, R405.1, U401.5 (FB)
/04_power_usb/BUCK_RIPPLE: C406.1, C407.1, R406.2
/04_power_usb/BUCK_RON: R403.1, U401.4 (RON)
/04_power_usb/BUCK_SW: C403.2, L401.1, R406.1, U401.8 (SW)
/04_power_usb/BUS_5V_GOOD: R407.2, U401.6 (PGOOD)
/04_power_usb/VDD_FB: R417.2, R418.1, U403.2 (FB)
PWR_BUS_SELECTED: R410.2, U402.8 (ST); also elsewhere on the board
VBUS: C401.1, C402.1, R401.1, U401.2 (VIN); also elsewhere on the board

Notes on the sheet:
Power supplies
Bus supply / LM5164, nominal 5 V
68 uH / about 300 kHz. R406, C406, C407 provide type-3 ripple injection. Verify startup and load transients.
Bus / USB selection and logic supply
3V3 net: 3.3605 V nominal (51.1k / 10k). USB-only: bridge disarmed; sensor supplies off at boot.

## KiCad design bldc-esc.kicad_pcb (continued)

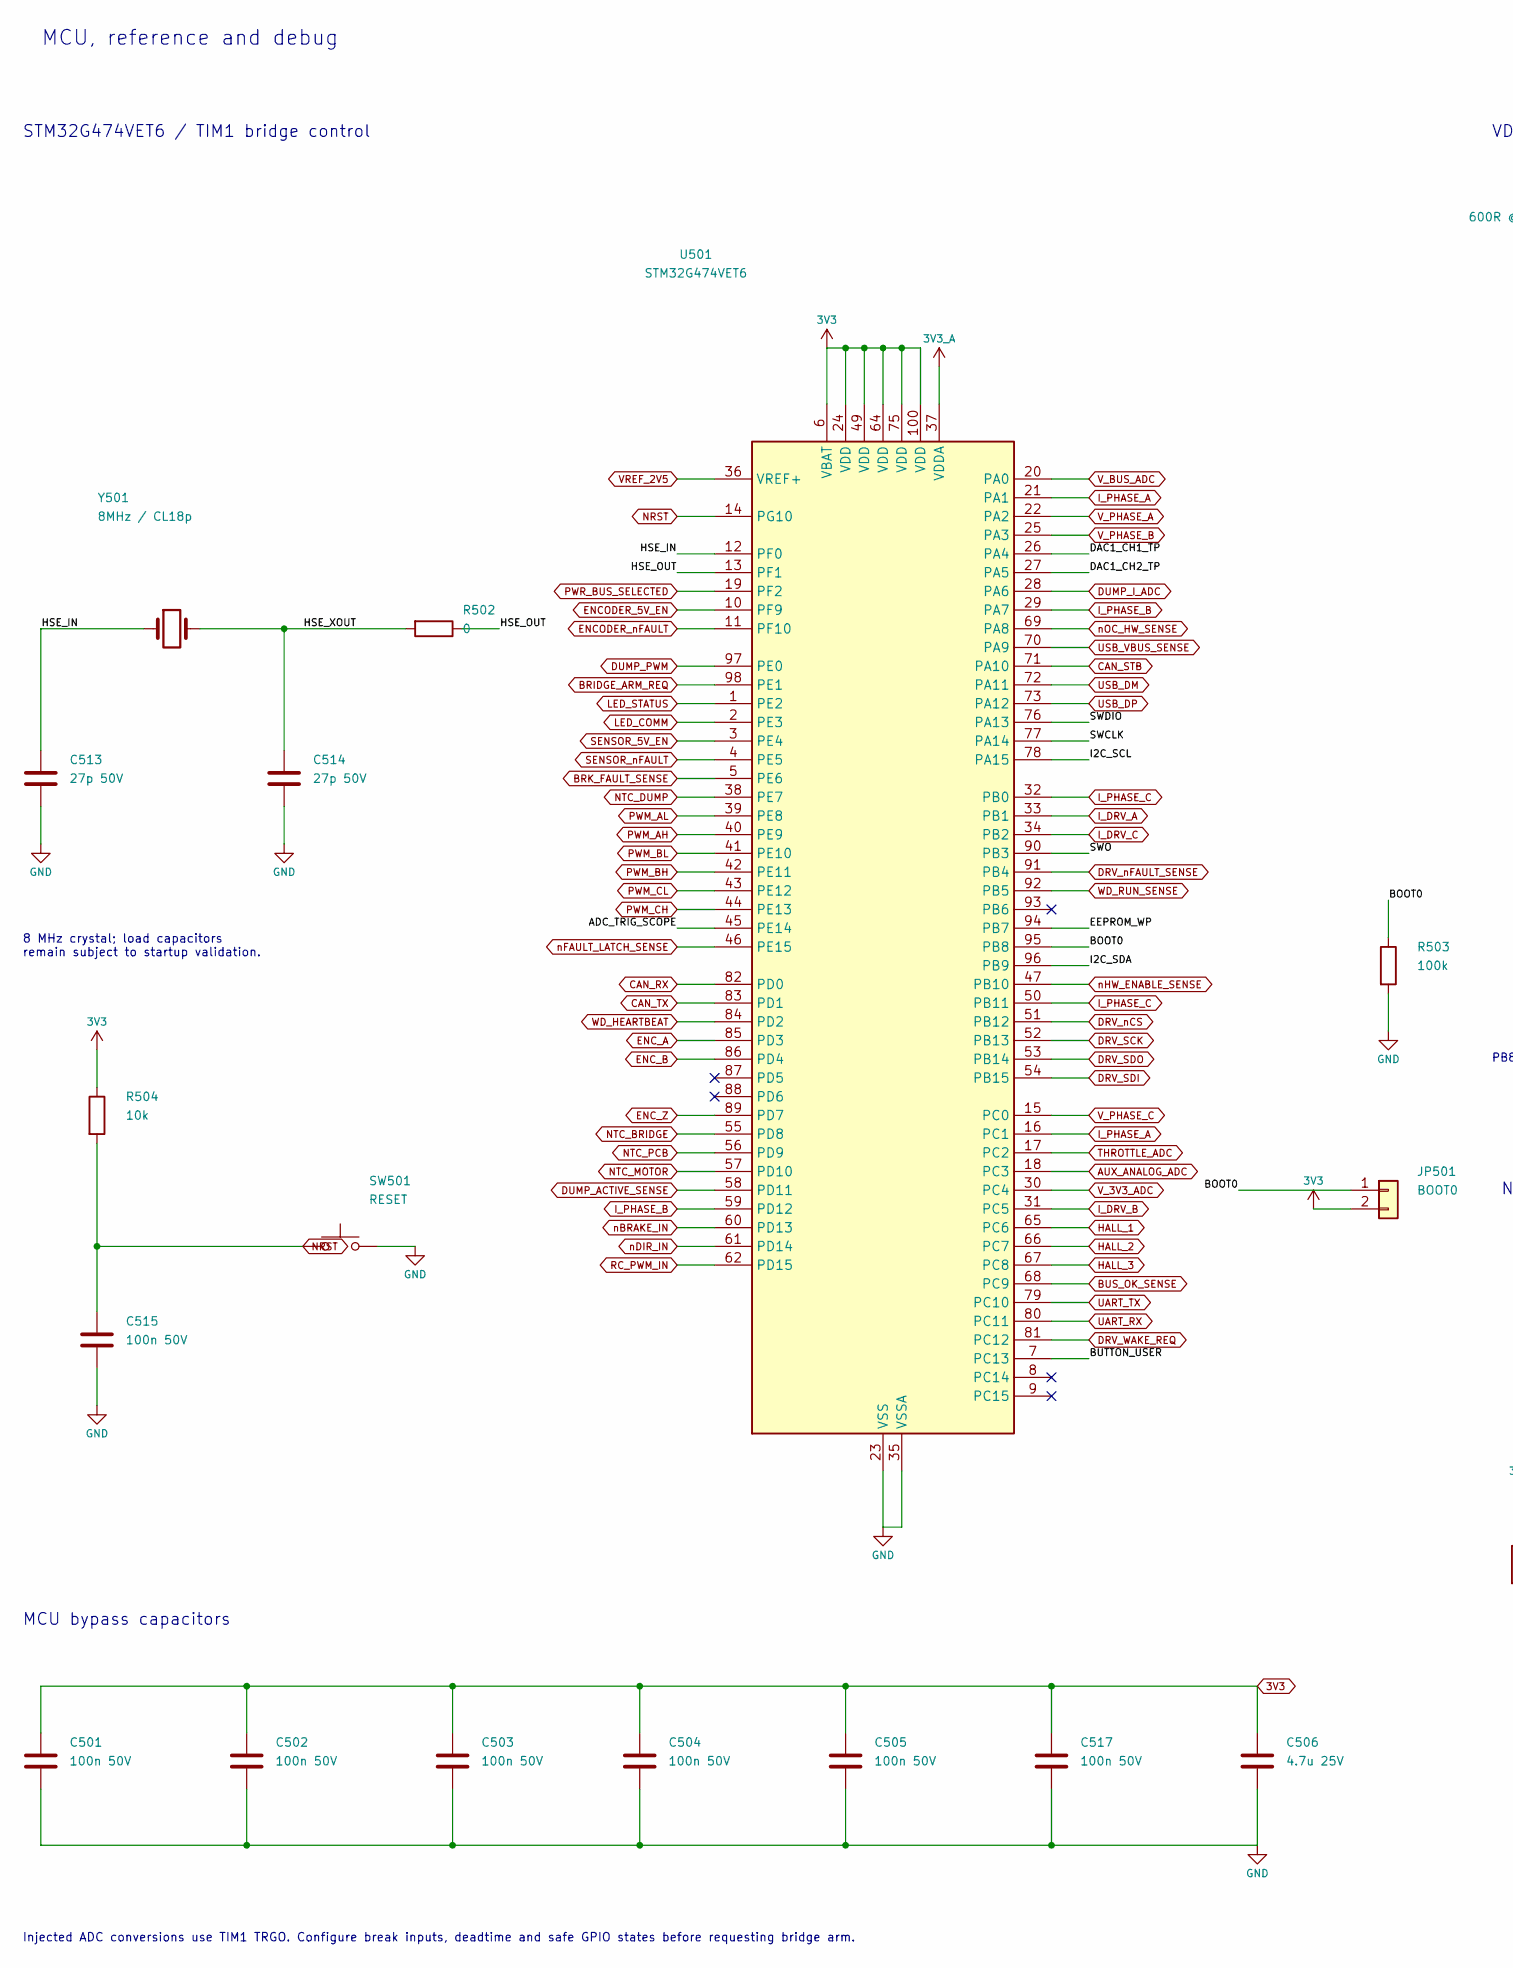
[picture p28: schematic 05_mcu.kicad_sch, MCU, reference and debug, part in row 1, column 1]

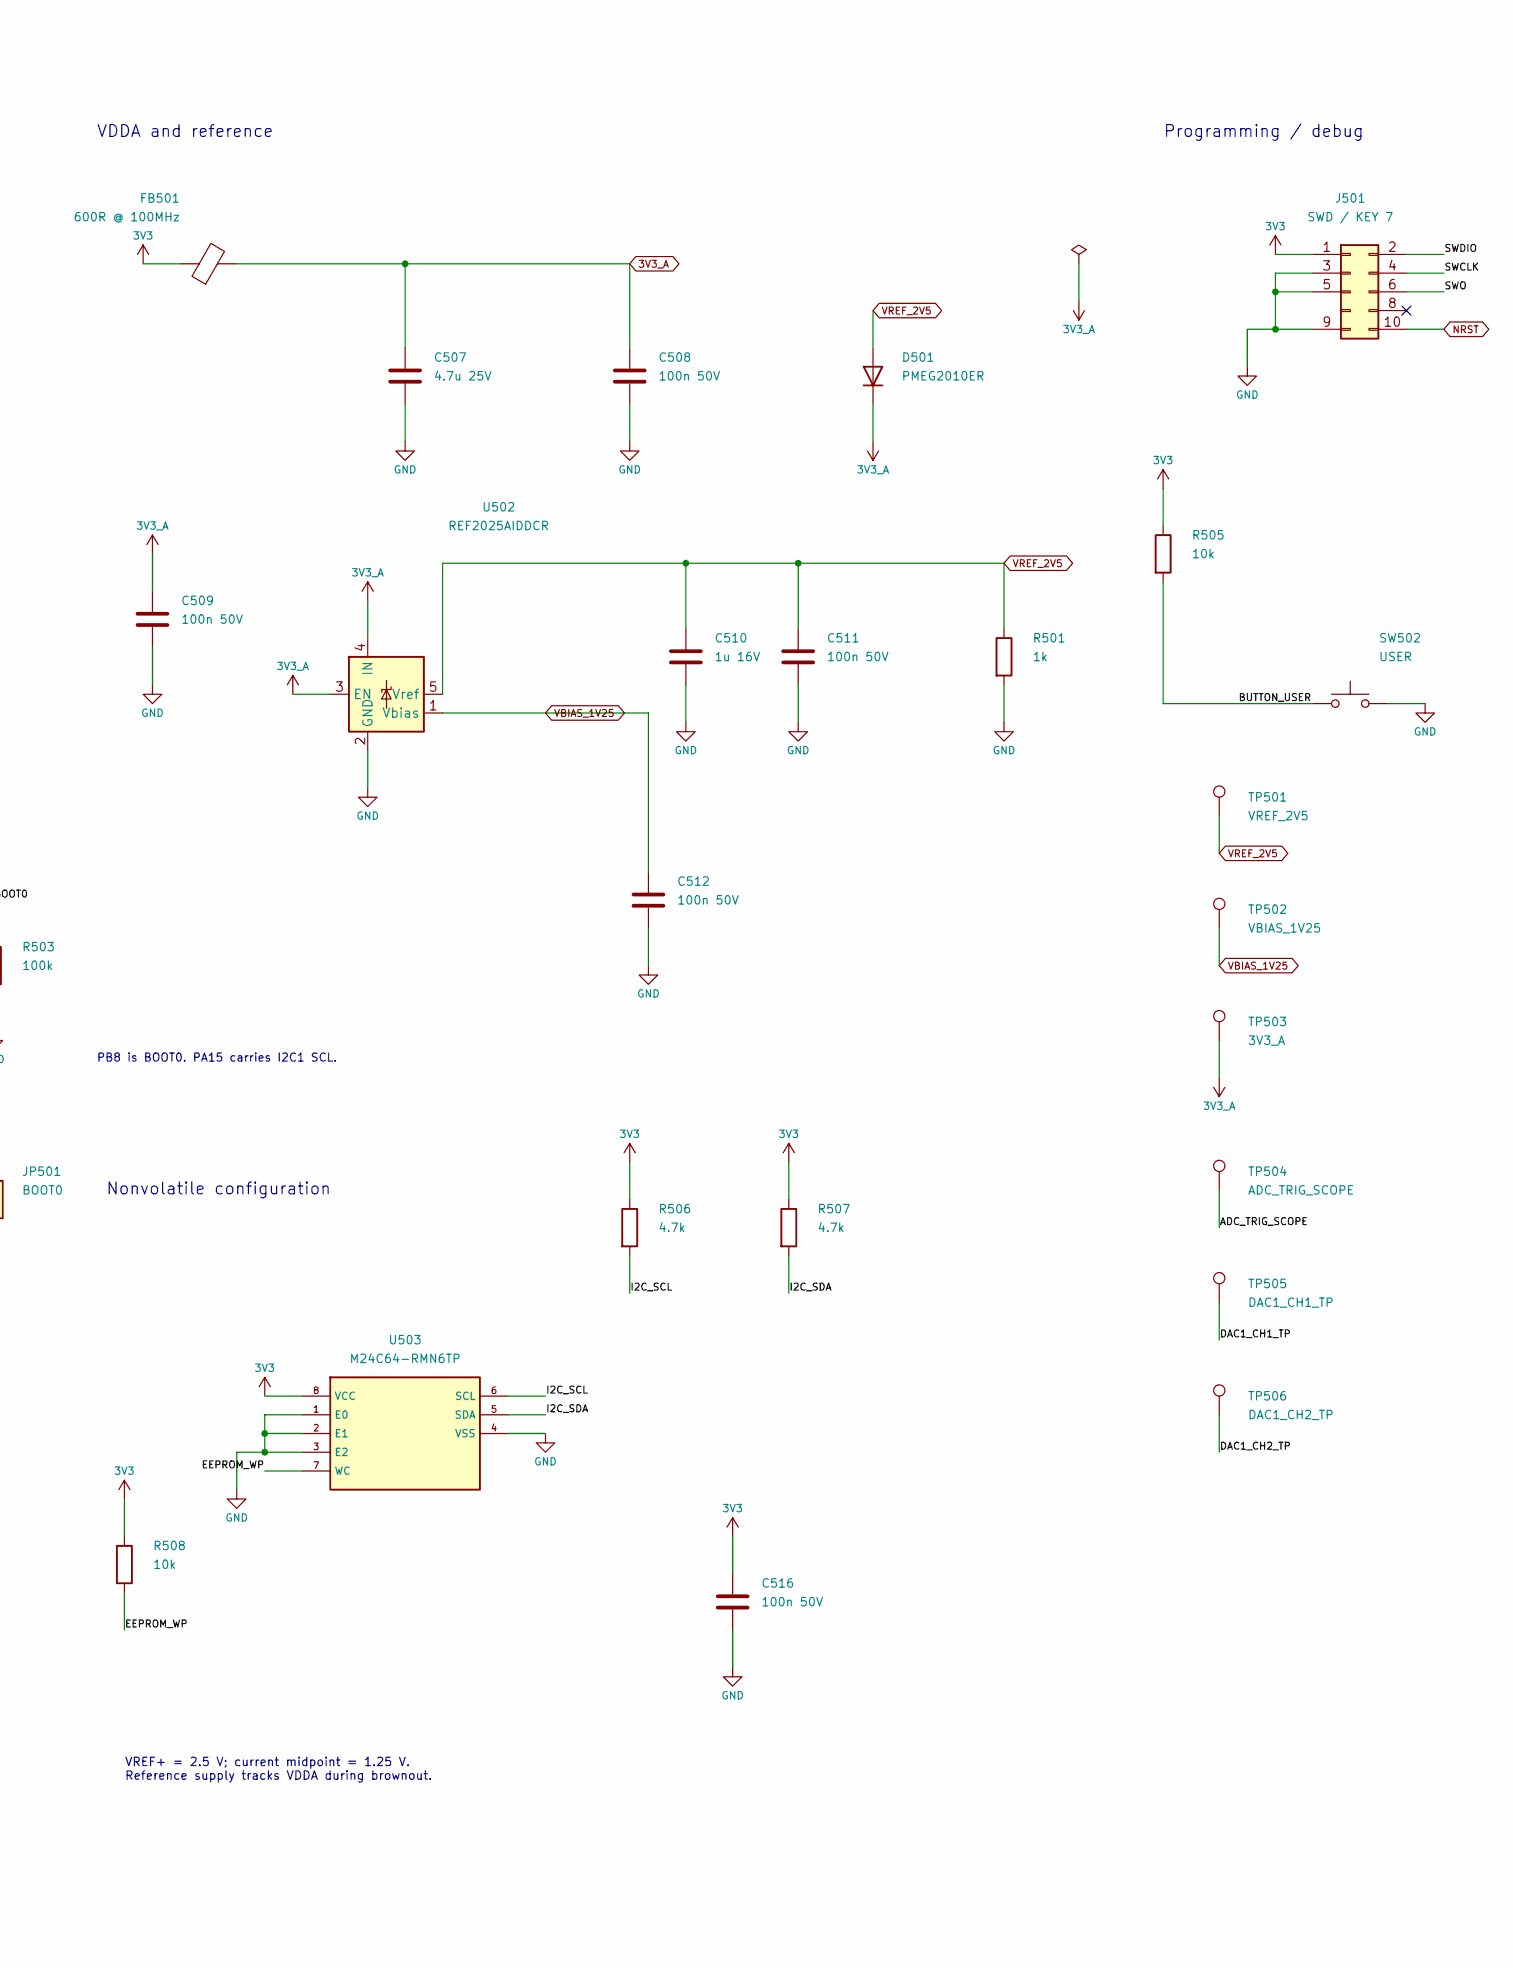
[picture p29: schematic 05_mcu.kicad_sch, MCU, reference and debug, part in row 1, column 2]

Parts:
C501, C502, C503, C504, C505, C508, C509, C511, C512, C515, C516, C517: 100n 50V; C_0603_1608Metric; MPN C0603C104K5RACTU
C506, C507: 4.7u 25V; C_0805_2012Metric; MPN C0805C475K3RACTU
C510: 1u 16V; C_0603_1608Metric; MPN C0603C105K4RACTU
C513, C514: 27p 50V; C_0603_1608Metric; MPN C0603C270J5GACTU
D501: PMEG2010ER; Nexperia_CFP3_SOD-123W; MPN PMEG2010ER,115
FB501: 600R @ 100MHz; L_0603_1608Metric; MPN BLM18KG601SN1D
J501: SWD / KEY 7; FTSH_105_DV_007_K; MPN FTSH-105-01-L-DV-007-K
JP501: BOOT0; PinHeader_1x02_P2.54mm_Vertical; MPN M20-9990245
R501: 1k; R_0603_1608Metric; MPN RC0603FR-071KL
R502: 0; R_0603_1608Metric; MPN RC0603JR-070RL
R503: 100k; R_0603_1608Metric; MPN RC0603FR-07100KL
R504, R505, R508: 10k; R_0603_1608Metric; MPN RC0603FR-0710KL
R506, R507: 4.7k; R_0603_1608Metric; MPN RC0603FR-074K7L
SW501: RESET; SW_SPST_TL3342; MPN TL3342F160QG
SW502: USER; SW_SPST_TL3342; MPN TL3342F160QG
TP501: VREF_2V5; TestPoint_Pad_D1.5mm; MPN TESTPOINT
TP502: VBIAS_1V25; TestPoint_Pad_D1.5mm; MPN TESTPOINT
TP503: 3V3_A; TestPoint_Pad_D1.5mm; MPN TESTPOINT
TP504: ADC_TRIG_SCOPE; TestPoint_Pad_D1.5mm; MPN TESTPOINT
TP505: DAC1_CH1_TP; TestPoint_Pad_D1.5mm; MPN TESTPOINT
TP506: DAC1_CH2_TP; TestPoint_Pad_D1.5mm; MPN TESTPOINT
U501: STM32G474VET6; LQFP-100_14x14mm_P0.5mm; MPN STM32G474VET6
U502: REF2025AIDDCR; SOT-23-5; MPN REF2025AIDDCR
U503: M24C64-RMN6TP; SOIC-8_3.9x4.9mm_P1.27mm; MPN M24C64-RMN6TP
Y501: 8MHz / CL18p; Crystal_SMD_Abracon_ABM3-2Pin_5.0x3.2mm; MPN ABM3-8.000MHZ-D2Y-T

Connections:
3V3: C501.1, C502.1, C503.1, C504.1, C505.1, C506.1, C516.1, C517.1, FB501.1, J501.1, JP501.2, R504.1, R505.1, R506.1, R507.1, R508.1, U501.6 (VBAT), U501.24 (VDD), U501.49 (VDD), U501.64 (VDD), U501.75 (VDD), U501.100 (VDD), U503.8 (VCC); also elsewhere on the board
3V3_A: C507.1, C508.1, C509.1, D501.1 (K), FB501.2, TP503.1 (1_1), U501.37 (VDDA), U502.3 (EN), U502.4 (IN); also elsewhere on the board
/05_mcu/ADC_TRIG_SCOPE: TP504.1 (1_1), U501.45 (PE14)
/05_mcu/BOOT0: JP501.1, R503.1, U501.95 (PB8)
/05_mcu/BUTTON_USER: R505.2, SW502.1, U501.7 (PC13)
/05_mcu/DAC1_CH1_TP: TP505.1 (1_1), U501.26 (PA4)
/05_mcu/DAC1_CH2_TP: TP506.1 (1_1), U501.27 (PA5)
/05_mcu/EEPROM_WP: R508.2, U501.94 (PB7), U503.7 (WC)
/05_mcu/HSE_IN: C513.1, U501.12 (PF0), Y501.1
/05_mcu/HSE_OUT: R502.1, U501.13 (PF1)
/05_mcu/HSE_XOUT: C514.1, R502.2, Y501.2
/05_mcu/I2C_SCL: R506.2, U501.78 (PA15), U503.6 (SCL)
/05_mcu/I2C_SDA: R507.2, U501.96 (PB9), U503.5 (SDA)
/05_mcu/SWCLK: J501.4, U501.77 (PA14)
/05_mcu/SWDIO: J501.2, U501.76 (PA13)
/05_mcu/SWO: J501.6, U501.90 (PB3)
AUX_ANALOG_ADC: U501.18 (PC3); also elsewhere on the board
BRIDGE_ARM_REQ: U501.98 (PE1); also elsewhere on the board
BRK_FAULT_SENSE: U501.5 (PE6); also elsewhere on the board
BUS_OK_SENSE: U501.68 (PC9); also elsewhere on the board
CAN_RX: U501.82 (PD0); also elsewhere on the board
CAN_STB: U501.71 (PA10); also elsewhere on the board
CAN_TX: U501.83 (PD1); also elsewhere on the board
DRV_SCK: U501.52 (PB13); also elsewhere on the board
DRV_SDI: U501.54 (PB15); also elsewhere on the board
DRV_SDO: U501.53 (PB14); also elsewhere on the board
DRV_WAKE_REQ: U501.81 (PC12); also elsewhere on the board
DRV_nCS: U501.51 (PB12); also elsewhere on the board
DRV_nFAULT_SENSE: U501.91 (PB4); also elsewhere on the board
DUMP_ACTIVE_SENSE: U501.58 (PD11); also elsewhere on the board
DUMP_I_ADC: U501.28 (PA6); also elsewhere on the board
DUMP_PWM: U501.97 (PE0); also elsewhere on the board
ENCODER_5V_EN: U501.10 (PF9); also elsewhere on the board
ENCODER_nFAULT: U501.11 (PF10); also elsewhere on the board
ENC_A: U501.85 (PD3); also elsewhere on the board
ENC_B: U501.86 (PD4); also elsewhere on the board
ENC_Z: U501.89 (PD7); also elsewhere on the board
HALL_1: U501.65 (PC6); also elsewhere on the board
HALL_2: U501.66 (PC7); also elsewhere on the board
HALL_3: U501.67 (PC8); also elsewhere on the board
I_DRV_A: U501.33 (PB1); also elsewhere on the board
I_DRV_B: U501.31 (PC5); also elsewhere on the board
I_DRV_C: U501.34 (PB2); also elsewhere on the board
I_PHASE_A: U501.16 (PC1), U501.21 (PA1); also elsewhere on the board
I_PHASE_B: U501.29 (PA7), U501.59 (PD12); also elsewhere on the board
I_PHASE_C: U501.32 (PB0), U501.50 (PB11); also elsewhere on the board
LED_COMM: U501.2 (PE3); also elsewhere on the board
LED_STATUS: U501.1 (PE2); also elsewhere on the board
NRST: C515.1, J501.10, R504.2, SW501.1, U501.14 (PG10); also elsewhere on the board
NTC_BRIDGE: U501.55 (PD8); also elsewhere on the board
NTC_DUMP: U501.38 (PE7); also elsewhere on the board
NTC_MOTOR: U501.57 (PD10); also elsewhere on the board
NTC_PCB: U501.56 (PD9); also elsewhere on the board
PWM_AH: U501.40 (PE9); also elsewhere on the board
PWM_AL: U501.39 (PE8); also elsewhere on the board
PWM_BH: U501.42 (PE11); also elsewhere on the board
PWM_BL: U501.41 (PE10); also elsewhere on the board
PWM_CH: U501.44 (PE13); also elsewhere on the board
PWM_CL: U501.43 (PE12); also elsewhere on the board
PWR_BUS_SELECTED: U501.19 (PF2); also elsewhere on the board
RC_PWM_IN: U501.62 (PD15); also elsewhere on the board
SENSOR_5V_EN: U501.3 (PE4); also elsewhere on the board
SENSOR_nFAULT: U501.4 (PE5); also elsewhere on the board
THROTTLE_ADC: U501.17 (PC2); also elsewhere on the board
UART_RX: U501.80 (PC11); also elsewhere on the board
UART_TX: U501.79 (PC10); also elsewhere on the board
USB_DM: U501.72 (PA11); also elsewhere on the board
USB_DP: U501.73 (PA12); also elsewhere on the board
USB_VBUS_SENSE: U501.70 (PA9); also elsewhere on the board
VBIAS_1V25: C512.1, TP502.1 (1_1), U502.1 (Vbias); also elsewhere on the board
VREF_2V5: C510.1, C511.1, D501.2 (A), R501.1, TP501.1 (1_1), U501.36 (VREF+), U502.5 (Vref); also elsewhere on the board
V_3V3_ADC: U501.30 (PC4); also elsewhere on the board
V_BUS_ADC: U501.20 (PA0); also elsewhere on the board
V_PHASE_A: U501.22 (PA2); also elsewhere on the board
V_PHASE_B: U501.25 (PA3); also elsewhere on the board
V_PHASE_C: U501.15 (PC0); also elsewhere on the board
WD_HEARTBEAT: U501.84 (PD2); also elsewhere on the board
WD_RUN_SENSE: U501.92 (PB5); also elsewhere on the board
nBRAKE_IN: U501.60 (PD13); also elsewhere on the board
nDIR_IN: U501.61 (PD14); also elsewhere on the board
nFAULT_LATCH_SENSE: U501.46 (PE15); also elsewhere on the board
nHW_ENABLE_SENSE: U501.47 (PB10); also elsewhere on the board
nOC_HW_SENSE: U501.69 (PA8); also elsewhere on the board

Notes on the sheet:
MCU, reference and debug
STM32G474VET6 / TIM1 bridge control
VDDA and reference
MCU bypass capacitors
8 MHz crystal; load capacitors remain subject to startup validation.
PB8 is BOOT0. PA15 carries I2C1 SCL.
Nonvolatile configuration
Programming / debug
VREF+ = 2.5 V; current midpoint = 1.25 V. Reference supply tracks VDDA during brownout.
Injected ADC conversions use TIM1 TRGO. Configure break inputs, deadtime and safe GPIO states before requesting bridge arm.

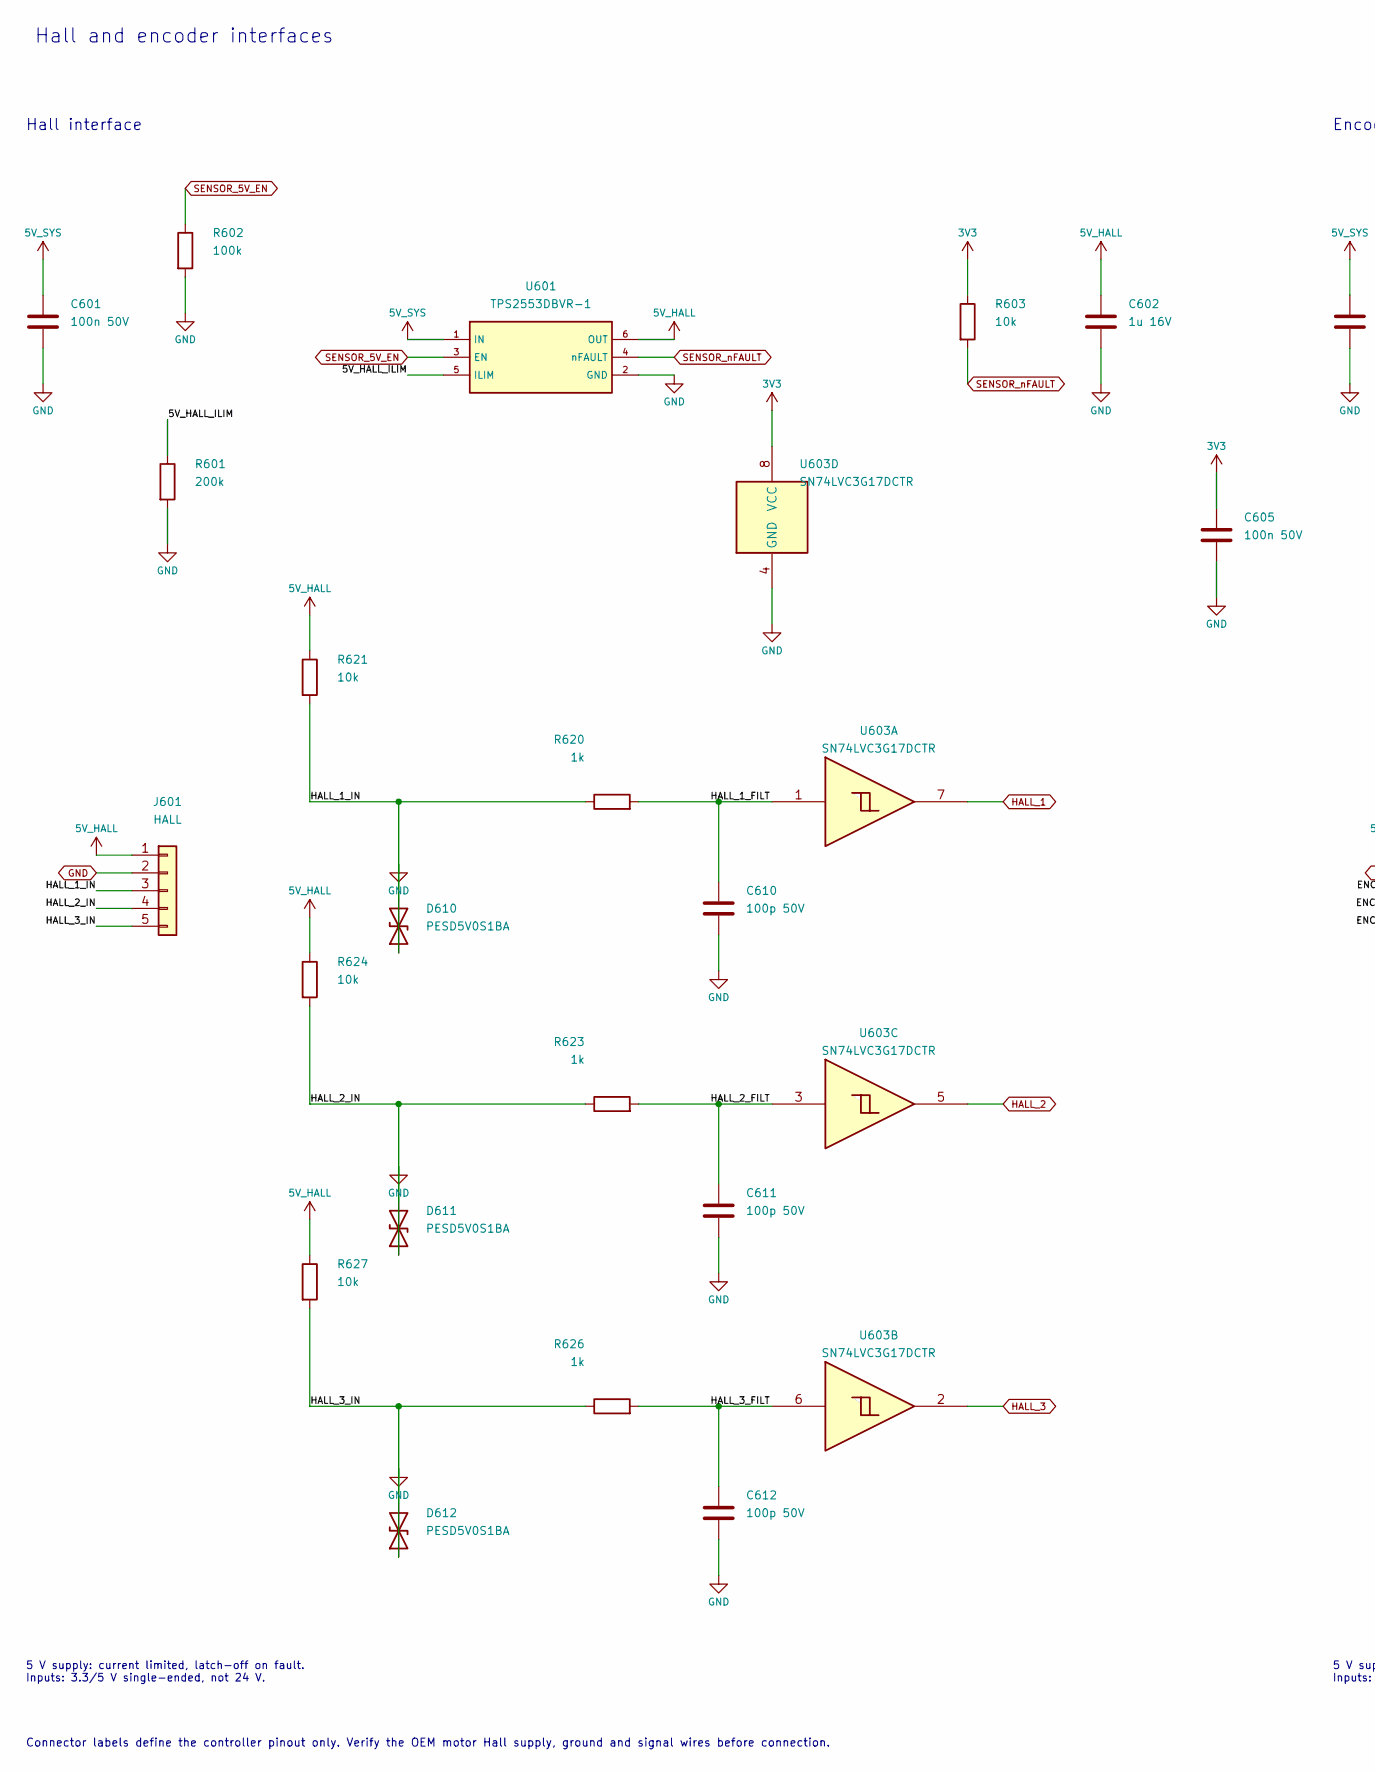
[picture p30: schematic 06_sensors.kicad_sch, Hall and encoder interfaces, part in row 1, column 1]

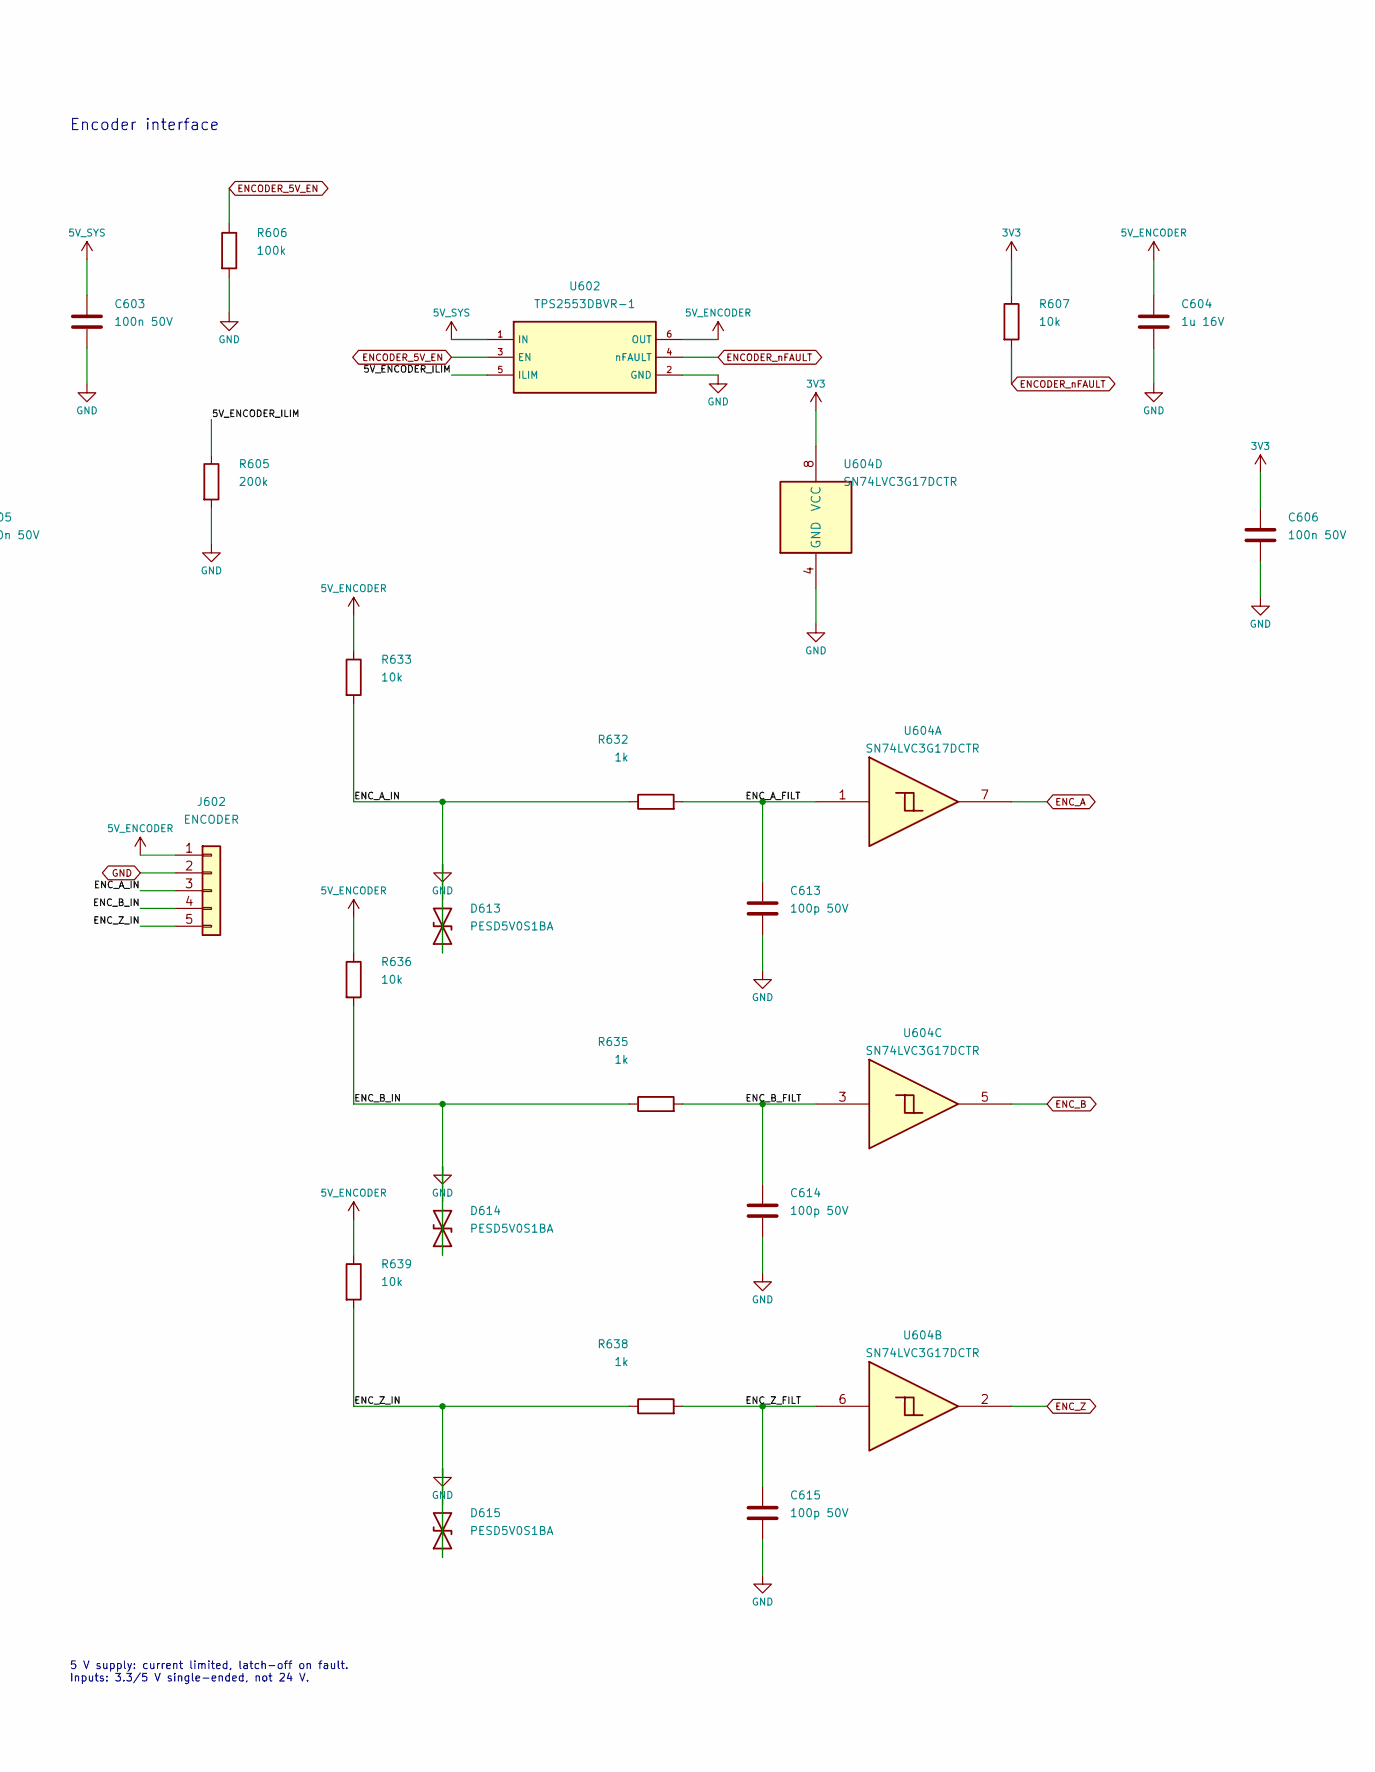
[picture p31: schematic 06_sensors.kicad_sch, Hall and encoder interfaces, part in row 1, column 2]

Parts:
C601, C603, C605, C606: 100n 50V; C_0603_1608Metric; MPN C0603C104K5RACTU
C602, C604: 1u 16V; C_0603_1608Metric; MPN C0603C105K4RACTU
C610, C611, C612, C613, C614, C615: 100p 50V; C_0603_1608Metric; MPN C0603C101J5GACTU
D610, D611, D612, D613, D614, D615: PESD5V0S1BA; D_SOD-323; MPN PESD5V0S1BA,115
J601: HALL; JST_GH_BM05B-GHS-TBT_1x05-1MP_P1.25mm_Vertical; MPN BM05B-GHS-TBT(LF)(SN)
J602: ENCODER; JST_GH_BM05B-GHS-TBT_1x05-1MP_P1.25mm_Vertical; MPN BM05B-GHS-TBT(LF)(SN)
R601, R605: 200k; R_0603_1608Metric; MPN RC0603FR-07200KL
R602, R606: 100k; R_0603_1608Metric; MPN RC0603FR-07100KL
R603, R607, R621, R624, R627, R633, R636, R639: 10k; R_0603_1608Metric; MPN RC0603FR-0710KL
R620, R623, R626, R632, R635, R638: 1k; R_0603_1608Metric; MPN RC0603FR-071KL
U601, U602: TPS2553DBVR-1; SOT-23-6; MPN TPS2553DBVR-1
U603, U604: SN74LVC3G17DCTR; SSOP-8_2.95x2.8mm_P0.65mm; MPN SN74LVC3G17DCTR

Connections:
3V3: C605.1, C606.1, R603.1, R607.1, U603.8 (VCC), U604.8 (VCC); also elsewhere on the board
5V_ENCODER: C604.1, J602.1, R633.1, R636.1, R639.1, U602.6 (OUT)
5V_HALL: C602.1, J601.1, R621.1, R624.1, R627.1, U601.6 (OUT); also elsewhere on the board
5V_SYS: C601.1, C603.1, U601.1 (IN), U602.1 (IN); also elsewhere on the board
/06_sensors/5V_ENCODER_ILIM: R605.1, U602.5 (ILIM)
/06_sensors/5V_HALL_ILIM: R601.1, U601.5 (ILIM)
/06_sensors/ENC_A_FILT: C613.1, R632.2, U604.1
/06_sensors/ENC_B_FILT: C614.1, R635.2, U604.3
/06_sensors/ENC_Z_FILT: C615.1, R638.2, U604.6
/06_sensors/HALL_1_FILT: C610.1, R620.2, U603.1
/06_sensors/HALL_2_FILT: C611.1, R623.2, U603.3
/06_sensors/HALL_3_FILT: C612.1, R626.2, U603.6
ENCODER_5V_EN: R606.1, U602.3 (EN); also elsewhere on the board
ENCODER_nFAULT: R607.2, U602.4 (nFAULT); also elsewhere on the board
ENC_A: U604.7; also elsewhere on the board
ENC_B: U604.5; also elsewhere on the board
ENC_Z: U604.2; also elsewhere on the board
HALL_1: U603.7; also elsewhere on the board
HALL_2: U603.5; also elsewhere on the board
HALL_3: U603.2; also elsewhere on the board
SENSOR_5V_EN: R602.1, U601.3 (EN); also elsewhere on the board
SENSOR_nFAULT: R603.2, U601.4 (nFAULT); also elsewhere on the board

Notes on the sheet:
Hall and encoder interfaces
Hall interface
5 V supply: current limited, latch-off on fault. Inputs: 3.3/5 V single-ended, not 24 V.
Encoder interface
Connector labels define the controller pinout only. Verify the OEM motor Hall supply, ground and signal wires before connection.

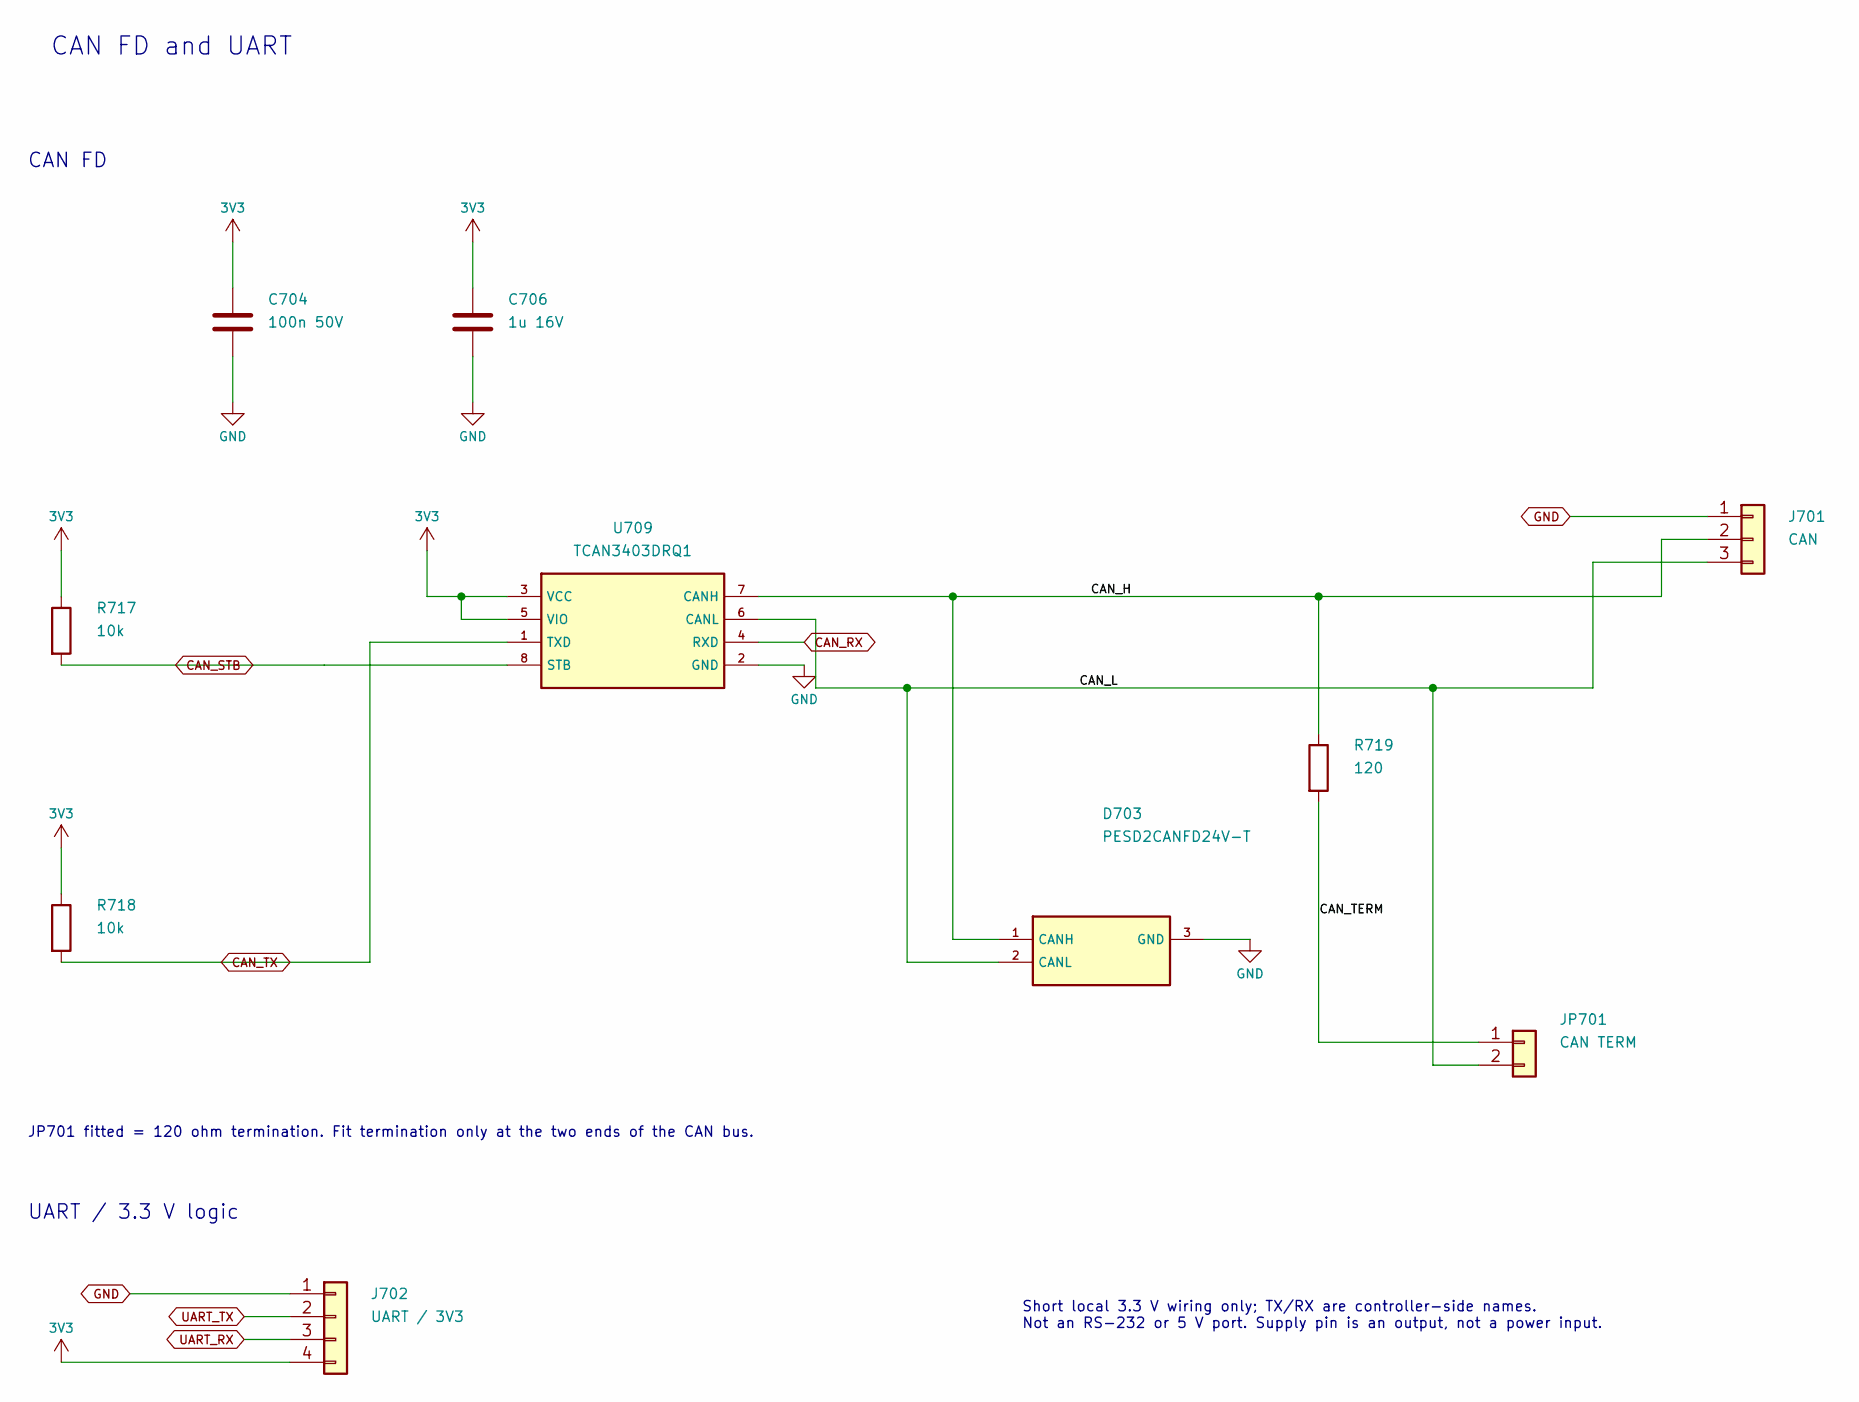
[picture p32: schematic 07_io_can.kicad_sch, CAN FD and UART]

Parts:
C704: 100n 50V; C_0603_1608Metric; MPN C0603C104K5RACTU
C706: 1u 16V; C_0603_1608Metric; MPN C0603C105K4RACTU
D703: PESD2CANFD24V-T; SOT-23; MPN PESD2CANFD24V-T,215
J701: CAN; JST_GH_BM03B-GHS-TBT_1x03-1MP_P1.25mm_Vertical; MPN BM03B-GHS-TBT(LF)(SN)
J702: UART / 3V3; JST_GH_BM04B-GHS-TBT_1x04-1MP_P1.25mm_Vertical; MPN BM04B-GHS-TBT(LF)(SN)
JP701: CAN TERM; PinHeader_1x02_P2.54mm_Vertical; MPN M20-9990245
R717, R718: 10k; R_0603_1608Metric; MPN RC0603FR-0710KL
R719: 120; R_0805_2012Metric; MPN RC0805FR-07120RL
U709: TCAN3403DRQ1; SOIC-8_3.9x4.9mm_P1.27mm; MPN TCAN3403DRQ1

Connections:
3V3: C704.1, C706.1, J702.4, R717.1, R718.1, U709.3 (VCC), U709.5 (VIO); also elsewhere on the board
/07_io_can/CAN_H: D703.1 (CANH), J701.2, R719.1, U709.7 (CANH)
/07_io_can/CAN_L: D703.2 (CANL), J701.3, JP701.2, U709.6 (CANL)
/07_io_can/CAN_TERM: JP701.1, R719.2
CAN_RX: U709.4 (RXD); also elsewhere on the board
CAN_STB: R717.2, U709.8 (STB); also elsewhere on the board
CAN_TX: R718.2, U709.1 (TXD); also elsewhere on the board
UART_RX: J702.3; also elsewhere on the board
UART_TX: J702.2; also elsewhere on the board

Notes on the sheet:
CAN FD and UART
CAN FD
JP701 fitted = 120 ohm termination. Fit termination only at the two ends of the CAN bus.
UART / 3.3 V logic
Short local 3.3 V wiring only; TX/RX are controller-side names. Not an RS-232 or 5 V port. Supply pin is an output, not a power input.

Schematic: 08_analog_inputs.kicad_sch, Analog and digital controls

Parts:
C845, C847: 100n 50V; C_0603_1608Metric; MPN C0603C104K5RACTU
C850, C855: 10n 50V; C_0603_1608Metric; MPN C0603C103K5RACTU
C852, C857, C865, C868, C871: 1n 50V; C_0603_1608Metric; MPN C0603C102J5GACTU
D850, D855: BAV199; SOT-23; MPN BAV199,215
D852, D857, D865, D868, D871: PESD5V0S1BA; D_SOD-323; MPN PESD5V0S1BA,115
J801: THROTTLE_ADC; JST_GH_BM03B-GHS-TBT_1x03-1MP_P1.25mm_Vertical; MPN BM03B-GHS-TBT(LF)(SN)
J802: AUX_ANALOG_ADC; JST_GH_BM03B-GHS-TBT_1x03-1MP_P1.25mm_Vertical; MPN BM03B-GHS-TBT(LF)(SN)
J803: RC PWM; JST_GH_BM03B-GHS-TBT_1x03-1MP_P1.25mm_Vertical; MPN BM03B-GHS-TBT(LF)(SN)
J804: BRAKE / DIR; JST_GH_BM03B-GHS-TBT_1x03-1MP_P1.25mm_Vertical; MPN BM03B-GHS-TBT(LF)(SN)
R850, R855: 12.1k; R_0603_1608Metric; MPN RC0603FR-0712K1L
R851, R856, R866, R869, R872: 10k; R_0603_1608Metric; MPN RC0603FR-0710KL
R852, R857: 100; R_0603_1608Metric; MPN RC0603FR-07100RL
R865, R868, R871: 1k; R_0603_1608Metric; MPN RC0603FR-071KL
U802: SN74LVC3G17DCTR; SSOP-8_2.95x2.8mm_P0.65mm; MPN SN74LVC3G17DCTR
U803: TLV9062IDR; SOIC-8_3.9x4.9mm_P1.27mm; MPN TLV9062IDR

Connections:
3V3: C845.1, R869.1, R872.1, U802.8 (VCC); also elsewhere on the board
3V3_A: C847.1, D850.2 (K), D855.2 (K), U803.8 (V+); also elsewhere on the board
5V_HALL: J801.1, J802.1, J803.2; also elsewhere on the board
/08_analog_inputs/AUX_ANALOG_ADC_BUF: R857.1, U803.6 (-), U803.7
/08_analog_inputs/AUX_ANALOG_ADC_DIV: C855.1, D855.3 (common), R855.2, R856.1, U803.5 (+)
/08_analog_inputs/RC_PWM_RAW_FILT: C865.1, R865.2, U802.1
/08_analog_inputs/THROTTLE_ADC_BUF: R852.1, U803.1, U803.2 (-)
/08_analog_inputs/THROTTLE_ADC_DIV: C850.1, D850.3 (common), R850.2, R851.1, U803.3 (+)
/08_analog_inputs/nBRAKE_RAW_FILT: C868.1, R868.2, U802.3
/08_analog_inputs/nDIR_RAW_FILT: C871.1, R871.2, U802.6
AUX_ANALOG_ADC: C857.1, R857.2; also elsewhere on the board
RC_PWM_IN: U802.7; also elsewhere on the board
THROTTLE_ADC: C852.1, R852.2; also elsewhere on the board
nBRAKE_IN: U802.5; also elsewhere on the board
nDIR_IN: U802.2; also elsewhere on the board

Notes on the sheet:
Analog and digital controls
Analog controls / 0-5 V input
Digital controls / 3.3 or 5 V logic

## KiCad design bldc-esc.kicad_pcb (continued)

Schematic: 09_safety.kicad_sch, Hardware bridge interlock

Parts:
C711, C712, C713, C714, C715, C716, C719, C720: 100n 50V; C_0603_1608Metric; MPN C0603C104K5RACTU
R705, R707, R708, R716, R724, R725: 100k; R_0603_1608Metric; MPN RC0603FR-07100KL
R706, R710, R711, R712, R713, R714, R715, R723: 10k; R_0603_1608Metric; MPN RC0603FR-0710KL
R709: 1k; R_0603_1608Metric; MPN RC0603FR-071KL
U703, U704, U707, U708, U711, U712: SN74LVC1G11DBVR; SOT-23-6; MPN SN74LVC1G11DBVR
U705: SN74LVC1G74DCTR; SSOP-8_2.95x2.8mm_P0.65mm; MPN SN74LVC1G74DCTR
U706: SN74LVC244APWR; TSSOP-20_4.4x6.5mm_P0.65mm; MPN SN74LVC244APWR

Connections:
3V3: C711.1, C712.1, C713.1, C714.1, C715.1, C716.1, C719.1, C720.1, R706.1, U703.5 (VCC), U704.5 (VCC), U705.2 (D), U705.7 (nPRE), U705.8 (VCC), U706.20 (VCC), U707.5 (VCC), U708.5 (VCC), U711.5 (VCC), U712.5 (VCC); also elsewhere on the board
/09_safety/DRV_ENABLE_PRE: U707.4, U712.1
/09_safety/SAFETY_GOOD: U704.4, U705.6 (nCLR)
/09_safety/SYSTEM_GOOD: U704.1, U711.4
/09_safety/SYSTEM_GOOD_PRE: U703.4, U711.1
/09_safety/nFAULT_LATCH: R709.1, U705.5 (Q), U708.6
/09_safety/nPWM_ENABLE: R706.2, U705.3 (nQ), U706.1 (nOE1), U706.19 (nOE2)
BRIDGE_ARM_REQ: R705.1, U705.1 (CLK); also elsewhere on the board
BRK_ARMED: U711.6, U712.6; also elsewhere on the board
BUS_OK: R708.1, U703.3, U707.6; also elsewhere on the board
BUS_OK_SENSE: R708.2; also elsewhere on the board
DRV_ENABLE: U712.4; also elsewhere on the board
DRV_WAKE_REQ: R716.1, U707.1; also elsewhere on the board
DRV_nFAULT: R725.1, U704.6; also elsewhere on the board
DRV_nFAULT_SENSE: R725.2; also elsewhere on the board
DUMP_PWM: U708.1; also elsewhere on the board
DUMP_PWM_SAFE: U708.4; also elsewhere on the board
HW_ENABLE_OK: U703.6; also elsewhere on the board
IN_AH: R710.1, U706.18 (Y1); also elsewhere on the board
IN_AL: R711.1, U706.16 (Y2); also elsewhere on the board
IN_BH: R712.1, U706.14 (Y3); also elsewhere on the board
IN_BL: R713.1, U706.12 (Y4); also elsewhere on the board
IN_CH: R714.1, U706.9 (Y5); also elsewhere on the board
IN_CL: R715.1, U706.7 (Y6); also elsewhere on the board
NRST: U703.1, U707.3, U708.3; also elsewhere on the board
PWM_AH: U706.2 (A1); also elsewhere on the board
PWM_AL: U706.4 (A2); also elsewhere on the board
PWM_BH: U706.6 (A3); also elsewhere on the board
PWM_BL: U706.8 (A4); also elsewhere on the board
PWM_CH: U706.11 (A5); also elsewhere on the board
PWM_CL: U706.13 (A6); also elsewhere on the board
WD_RUN: R723.1, U711.3, U712.3; also elsewhere on the board
WD_RUN_SENSE: R723.2; also elsewhere on the board
nFAULT_LATCH_SENSE: R709.2; also elsewhere on the board
nHW_ENABLE_FILT: R724.1; also elsewhere on the board
nHW_ENABLE_SENSE: R724.2; also elsewhere on the board
nOC_HW: R707.1, U704.3; also elsewhere on the board
nOC_HW_SENSE: R707.2; also elsewhere on the board

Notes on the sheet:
Hardware bridge interlock
Arm interlock / fault removal does not re-arm the bridge
Driver wake / independent chopper request
MCU monitoring / series isolation
Hardware fault and enable nodes are isolated from MCU GPIO drive. Disable UCPD dead-battery control before reading PB4.

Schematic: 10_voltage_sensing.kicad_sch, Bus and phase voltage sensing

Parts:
C801, C811, C821, C831: 220p 50V; C_0603_1608Metric; MPN C0603C221J5GACTU
C802, C812, C822, C832: 1n 50V; C_0603_1608Metric; MPN C0603C102J5GACTU
C840: 100n 50V; C_0603_1608Metric; MPN C0603C104K5RACTU
D801, D811, D821, D831: BAV199; SOT-23; MPN BAV199,215
R801, R802, R811, R812, R821, R822, R831, R832: 100k 0.1%; R_0603_1608Metric; MPN RT0603BRD07100KL
R803, R813, R823, R833: 10k 0.1%; R_0603_1608Metric; MPN RT0603BRD0710KL
R804, R814, R824, R834: 100; R_0603_1608Metric; MPN RC0603FR-07100RL
U801: TLV9064IPWR; TSSOP-14_4.4x5mm_P0.65mm; MPN TLV9064IPWR

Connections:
3V3_A: C840.1, D801.2 (K), D811.2 (K), D821.2 (K), D831.2 (K), U801.4 (V+); also elsewhere on the board
/10_voltage_sensing/V_BUS_ADC_BUF: R804.1, U801.1, U801.2 (-)
/10_voltage_sensing/V_BUS_ADC_DIV: C801.1, D801.3 (common), R802.2, R803.1, U801.3 (+)
/10_voltage_sensing/V_BUS_ADC_MID: R801.2, R802.1
/10_voltage_sensing/V_PHASE_A_BUF: R814.1, U801.6 (-), U801.7
/10_voltage_sensing/V_PHASE_A_DIV: C811.1, D811.3 (common), R812.2, R813.1, U801.5 (+)
/10_voltage_sensing/V_PHASE_A_MID: R811.2, R812.1
/10_voltage_sensing/V_PHASE_B_BUF: R824.1, U801.8, U801.9 (-)
/10_voltage_sensing/V_PHASE_B_DIV: C821.1, D821.3 (common), R822.2, R823.1, U801.10 (+)
/10_voltage_sensing/V_PHASE_B_MID: R821.2, R822.1
/10_voltage_sensing/V_PHASE_C_BUF: R834.1, U801.13 (-), U801.14
/10_voltage_sensing/V_PHASE_C_DIV: C831.1, D831.3 (common), R832.2, R833.1, U801.12 (+)
/10_voltage_sensing/V_PHASE_C_MID: R831.2, R832.1
PHASE_A: R811.1; also elsewhere on the board
PHASE_B: R821.1; also elsewhere on the board
PHASE_C: R831.1; also elsewhere on the board
VBUS: R801.1; also elsewhere on the board
V_BUS_ADC: C802.1, R804.2; also elsewhere on the board
V_PHASE_A: C812.1, R814.2; also elsewhere on the board
V_PHASE_B: C822.1, R824.2; also elsewhere on the board
V_PHASE_C: C832.1, R834.2; also elsewhere on the board

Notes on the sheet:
Bus and phase voltage sensing
Bus voltage
Phase A voltage
Phase B voltage
Phase C voltage
21:1 dividers; 2.5 V ADC full scale = 52.5 V at the input. Buffers isolate the dividers from ADC sampling transients. Normal operation remains limited to a 12-30 V bus.

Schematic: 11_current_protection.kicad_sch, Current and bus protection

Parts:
C110, C111, C112, C117: 10n 50V; C_0603_1608Metric; MPN C0603C103K5RACTU
C113, C114: 100n 50V; C_0603_1608Metric; MPN C0603C104K5RACTU
R110, R113, R114, R119: 10k 0.1%; R_0603_1608Metric; MPN RT0603BRD0710KL
R111, R112: 90.9k 0.1%; R_0603_1608Metric; MPN RT0603BRD0790K9L
R115: 16.9k 0.1%; R_0603_1608Metric; MPN RT0603BRD0716K9L
R116: 4.7k; R_0603_1608Metric; MPN RC0603FR-074K7L
R117: 10k; R_0603_1608Metric; MPN RC0603FR-0710KL
R118: 40.2k 0.1%; R_0603_1608Metric; MPN RT0603BRD0740K2L
U101, U102: TLV9024PWR; TSSOP-14_4.4x5mm_P0.65mm; MPN TLV9024PWR

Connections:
3V3: R116.1, R117.1; also elsewhere on the board
3V3_A: C113.1, C114.1, U101.3 (V+), U102.3 (V+); also elsewhere on the board
/11_current_protection/BUS_OV_REF: C112.1, R114.2, R115.1, U102.9 (+)
/11_current_protection/BUS_UV_REF: C117.1, R118.2, R119.1, U102.10 (-)
/11_current_protection/OC_HI: C110.1, R110.2, R111.1, U101.5 (+), U101.9 (+), U102.5 (+)
/11_current_protection/OC_LO: C111.1, R112.2, R113.1, U101.6 (-), U101.10 (-), U102.6 (-)
BUS_OK: R117.2, U102.13, U102.14; also elsewhere on the board
I_PHASE_A: U101.4 (-), U101.7 (+); also elsewhere on the board
I_PHASE_B: U101.8 (-), U101.11 (+); also elsewhere on the board
I_PHASE_C: U102.4 (-), U102.7 (+); also elsewhere on the board
VREF_2V5: R110.1, R112.1, R114.1, R118.1; also elsewhere on the board
V_BUS_ADC: U102.8 (-), U102.11 (+); also elsewhere on the board
nOC_HW: R116.2, U101.1, U101.2, U101.13, U101.14, U102.1, U102.2; also elsewhere on the board

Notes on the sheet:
Current and bus protection
Bipolar phase-current window
Phase A / upper
Phase A / lower
Phase B / upper
Phase B / lower
Phase C / upper
Phase C / lower
Current thresholds / about +/-50 A
Board protection only. Use lower motor limits. OEM motor: 0.75 A.
Bus window / about 10.5-33 V

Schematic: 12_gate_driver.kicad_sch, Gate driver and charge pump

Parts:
C201: 22u 63V; CP_Radial_D6.3mm_P2.50mm; MPN EEUFC1J220
C202: 100n 100V; C_0603_1608Metric; MPN C0603C104K1RACTU
C203: 47n 100V; C_0805_2012Metric; MPN C0805C473K1RACTU
C204: 1u 50V; C_1206_3216Metric; MPN C3216X7R1H105K160AB
C205: 1u 25V; C_0805_2012Metric; MPN C0805C105K3RACTU
C206: 1u 16V; C_0603_1608Metric; MPN C0603C105K4RACTU
C207: 100n 50V; C_0603_1608Metric; MPN C0603C104K5RACTU
R201: 2.2; R_0805_2012Metric; MPN RC0805FR-072R2L
R202: 4.7k; R_0603_1608Metric; MPN RC0603FR-074K7L
R203, R205: 10k; R_0603_1608Metric; MPN RC0603FR-0710KL
R204: 100k; R_0603_1608Metric; MPN RC0603FR-07100KL
U201: DRV8353SRTAT; DRV8353_RTA0040B; MPN DRV8353SRTAT

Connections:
3V3: R202.1, R203.1, R205.1; also elsewhere on the board
3V3_A: C207.1, U201.24 (VREF); also elsewhere on the board
/12_gate_driver/DRV_CPH: C203.1, U201.2 (CPH)
/12_gate_driver/DRV_CPL: C203.2, U201.1 (CPL)
/12_gate_driver/DRV_DVDD: C206.1, U201.38 (DVDD)
/12_gate_driver/DRV_VCP: C204.1, U201.5 (VCP)
/12_gate_driver/DRV_VGLS: C205.1, U201.40 (VGLS)
/12_gate_driver/DRV_VM: C201.1, C202.1, R201.2, U201.3 (VM)
DRV_ENABLE: R204.1, U201.31 (ENABLE); also elsewhere on the board
DRV_SCK: U201.29 (SCLK); also elsewhere on the board
DRV_SDI: U201.28 (SDI); also elsewhere on the board
DRV_SDO: R202.2, U201.27 (SDO); also elsewhere on the board
DRV_nCS: R205.2, U201.30 (nSCS); also elsewhere on the board
DRV_nFAULT: R203.2, U201.26 (nFAULT); also elsewhere on the board
GHA_DRV: U201.6 (GHA); also elsewhere on the board
GHB_DRV: U201.15 (GHB); also elsewhere on the board
GHC_DRV: U201.16 (GHC); also elsewhere on the board
GLA_DRV: U201.8 (GLA); also elsewhere on the board
GLB_DRV: U201.13 (GLB); also elsewhere on the board
GLC_DRV: U201.18 (GLC); also elsewhere on the board
IN_AH: U201.32 (INHA); also elsewhere on the board
IN_AL: U201.33 (INLA); also elsewhere on the board
IN_BH: U201.34 (INHB); also elsewhere on the board
IN_BL: U201.35 (INLB); also elsewhere on the board
IN_CH: U201.36 (INHC); also elsewhere on the board
IN_CL: U201.37 (INLC); also elsewhere on the board
KS_A_N: U201.10 (SNA); also elsewhere on the board
KS_B_N: U201.11 (SNB); also elsewhere on the board
KS_C_N: U201.20 (SNC); also elsewhere on the board
PHASE_A: U201.7 (SHA); also elsewhere on the board
PHASE_B: U201.14 (SHB); also elsewhere on the board
PHASE_C: U201.17 (SHC); also elsewhere on the board
SOURCE_A: U201.9 (SPA); also elsewhere on the board
SOURCE_B: U201.12 (SPB); also elsewhere on the board
SOURCE_C: U201.19 (SPC); also elsewhere on the board
SO_A_DRV: U201.23 (SOA); also elsewhere on the board
SO_B_DRV: U201.22 (SOB); also elsewhere on the board
SO_C_DRV: U201.21 (SOC); also elsewhere on the board
VBUS: C204.2, R201.1, U201.4 (VDRAIN); also elsewhere on the board

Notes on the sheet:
Gate driver and charge pump
Gate driver / charge pump
VM filter and pump capacitors belong next to U201. VCP reservoir returns to VBUS, not GND.
SPx returns directly to each low-side source. SNx / CSA inputs use Kelvin shunt sense pads.
Six PWM inputs arrive through the hardware arm interlock. ENABLE is separate for driver setup.

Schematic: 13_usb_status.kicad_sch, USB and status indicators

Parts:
C413: 100n 50V; C_0603_1608Metric; MPN C0603C104K5RACTU
D511: STATUS; LED_0603_1608Metric; MPN LTST-C190KGKT
D512: COMM; LED_0603_1608Metric; MPN LTST-C190KGKT
D513: POWER; LED_0603_1608Metric; MPN LTST-C190KGKT
F401: 0.5A / 6V; MF_PSMF0805; MPN MF-PSMF050X-2
J401: USB4105-GF-A; USB4105_PCBWay; MPN USB4105-GF-A
R411, R412: 5.1k; R_0603_1608Metric; MPN RC0603FR-075K1L
R413, R414: 22; R_0603_1608Metric; MPN RC0603FR-0722RL
R415: 10k; R_0603_1608Metric; MPN RC0603FR-0710KL
R416: 15k; R_0603_1608Metric; MPN RC0603FR-0715KL
R511, R512, R513: 1k; R_0603_1608Metric; MPN RC0603FR-071KL
TP401: 5V_BUS; TestPoint_Pad_D1.5mm; MPN TESTPOINT
TP402: 5V_SYS; TestPoint_Pad_D1.5mm; MPN TESTPOINT
TP403: 3V3; TestPoint_Pad_D1.5mm; MPN TESTPOINT
TP404: GND; TestPoint_Pad_D1.5mm; MPN TESTPOINT
U404: USBLC6-2SC6; SOT-23-6; MPN USBLC6-2SC6

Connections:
3V3: R513.1, TP403.1 (1_1); also elsewhere on the board
5V_BUS: TP401.1 (1_1); also elsewhere on the board
5V_SYS: TP402.1 (1_1); also elsewhere on the board
/13_usb_status/CC1: J401.A5 (CC1), R411.1
/13_usb_status/CC2: J401.B5 (CC2), R412.1
/13_usb_status/LED_1: D511.2 (A), R511.2
/13_usb_status/LED_2: D512.2 (A), R512.2
/13_usb_status/LED_3: D513.2 (A), R513.2
/13_usb_status/USB_DM_ESD: R414.1, U404.4 (I/O2)
/13_usb_status/USB_DM_PORT: J401.A7 (D-), J401.B7 (D-), U404.3 (I/O2)
/13_usb_status/USB_DP_ESD: R413.1, U404.6 (I/O1)
/13_usb_status/USB_DP_PORT: J401.A6 (D+), J401.B6 (D+), U404.1 (I/O1)
/13_usb_status/USB_VBUS_RAW: C413.1, F401.1, J401.A4 (VBUS), J401.A9 (VBUS), J401.B4 (VBUS), J401.B9 (VBUS), R415.1, U404.5 (VBUS)
CHASSIS: J401.SH (SHIELD); also elsewhere on the board
LED_COMM: R512.1; also elsewhere on the board
LED_STATUS: R511.1; also elsewhere on the board
USB_DM: R414.2; also elsewhere on the board
USB_DP: R413.2; also elsewhere on the board
USB_VBUS_SENSE: R415.2, R416.1; also elsewhere on the board

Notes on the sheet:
USB and status indicators
USB-C device port
Status / probe points
USB shield bonds to CHASSIS. D+/D- protection belongs close to the connector; 22 ohm resistors belong near the MCU.

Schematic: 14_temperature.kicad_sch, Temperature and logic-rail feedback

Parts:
C848: 100n 50V; C_0603_1608Metric; MPN C0603C104K5RACTU
C880, C883, C886, C889, C899: 10n 50V; C_0603_1608Metric; MPN C0603C103K5RACTU
C888, C891: 1n 50V; C_0603_1608Metric; MPN C0603C102J5GACTU
D886, D889: BAV199; SOT-23; MPN BAV199,215
D888, D891: PESD5V0S1BA; D_SOD-323; MPN PESD5V0S1BA,115
J805: NTC_MOTOR; JST_GH_BM02B-GHS-TBT_1x02-1MP_P1.25mm_Vertical; MPN BM02B-GHS-TBT(LF)(SN)
J806: NTC_DUMP; JST_GH_BM02B-GHS-TBT_1x02-1MP_P1.25mm_Vertical; MPN BM02B-GHS-TBT(LF)(SN)
R880, R883, R886, R889, R898, R899: 10k 0.1%; R_0603_1608Metric; MPN RT0603BRD0710KL
R887, R890: 1k; R_0603_1608Metric; MPN RC0603FR-071KL
R888, R891: 100; R_0603_1608Metric; MPN RC0603FR-07100RL
TH801, TH802: 10k / B25-50=3380K; R_0603_1608Metric; MPN NCP18XH103F03RB
U804: TLV9062IDR; SOIC-8_3.9x4.9mm_P1.27mm; MPN TLV9062IDR

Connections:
3V3: R898.1; also elsewhere on the board
3V3_A: C848.1, D886.2 (K), D889.2 (K), U804.8 (V+); also elsewhere on the board
/14_temperature/NTC_DUMP_BUF: R891.1, U804.6 (-), U804.7
/14_temperature/NTC_DUMP_DIV: C889.1, D889.3 (common), R889.2, R890.2, U804.5 (+)
/14_temperature/NTC_MOTOR_BUF: R888.1, U804.1, U804.2 (-)
/14_temperature/NTC_MOTOR_DIV: C886.1, D886.3 (common), R886.2, R887.2, U804.3 (+)
NTC_BRIDGE: C880.1, R880.2, TH801.1; also elsewhere on the board
NTC_DUMP: C891.1, R891.2; also elsewhere on the board
NTC_MOTOR: C888.1, R888.2; also elsewhere on the board
NTC_PCB: C883.1, R883.2, TH802.1; also elsewhere on the board
VREF_2V5: R880.1, R883.1, R886.1, R889.1; also elsewhere on the board
V_3V3_ADC: C899.1, R898.2, R899.1; also elsewhere on the board

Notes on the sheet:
Temperature and logic-rail feedback
Temperature feedback
TH801/TH802: 10k, B25/50=3380 K. External NTC conversion must subtract the 1k series resistor. External channels are buffered; configure their actual R/T curves before thermal-limit testing.

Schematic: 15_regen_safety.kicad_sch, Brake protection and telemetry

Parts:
C307, C309, C311: 100n 50V; C_0603_1608Metric; MPN C0603C104K5RACTU
C308: 1n 50V; C_0603_1608Metric; MPN C0603C102J5GACTU
C310: 10n 50V; C_0603_1608Metric; MPN C0603C103K5RACTU
C312: 100p 50V; C_0603_1608Metric; MPN C0603C101J5GACTU
D302, D303: BAT54H; D_SOD-123F; MPN BAT54H,115
R311, R312, R313: 10k; R_0603_1608Metric; MPN RC0603FR-0710KL
R314, R315, R317: 100k; R_0603_1608Metric; MPN RC0603FR-07100KL
R316, R318: 150k; R_0603_1608Metric; MPN RC0603FR-07150KL
R320: 10k 0.1%; R_0603_1608Metric; MPN RT0603BRD0710KL
R321: 15k 0.1%; R_0603_1608Metric; MPN RT0603BRD0715KL
U304: TLV3201AIDBVR; SOT-23-5; MPN TLV3201AIDBVR
U305: TPS3808G50DBVR; SOT-23-6; MPN TPS3808G50DBVR
U306: SN74LVC1G17DBVR; SOT-23-5; MPN SN74LVC1G17DBVR
U307: SN74LVC1G74DCTR; SSOP-8_2.95x2.8mm_P0.65mm; MPN SN74LVC1G74DCTR

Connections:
5V_BUS: C307.1, C309.1, C311.1, R311.1, R312.1, U304.5 (V+), U305.3 (nMR), U305.5 (SENSE), U305.6 (VDD), U306.5 (VCC), U307.2 (D), U307.7 (nPRE), U307.8 (VCC); also elsewhere on the board
/15_regen_safety/BRK_CLEAR: D302.2 (A), D303.2 (A), R311.2, U307.6 (nCLR)
/15_regen_safety/BRK_CLK: U306.4, U307.1 (CLK)
/15_regen_safety/BRK_CLK_RC: C310.1, R313.2, U306.2
/15_regen_safety/BRK_CT: C308.1, U305.4 (CT)
/15_regen_safety/BRK_OC_OK: D303.1 (K), U304.1 (OUT)
/15_regen_safety/BRK_POR: D302.1 (K), R312.2, R313.1, U305.1 (nRESET)
/15_regen_safety/nBRK_ARMED: R317.1, U307.3 (nQ)
BRK_ARMED: R314.1, U307.5 (Q); also elsewhere on the board
BRK_FAULT_SENSE: R317.2, R318.1; also elsewhere on the board
DUMP_ACTIVE_SENSE: R315.2, R316.1; also elsewhere on the board
DUMP_CURRENT: R320.1, U304.4 (IN-); also elsewhere on the board
DUMP_I_ADC: C312.1, R320.2, R321.1; also elsewhere on the board
DUMP_REF: U304.3 (IN+); also elsewhere on the board
nDUMP_REQUEST: R315.1; also elsewhere on the board

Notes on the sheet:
Brake protection and telemetry
5 V-to-3.3 V monitor dividers
Dump current: 36 mV/A to PA6 ADC2_IN3. Use a long regular ADC acquisition time.
Chopper overcurrent trip and power-cycle latch

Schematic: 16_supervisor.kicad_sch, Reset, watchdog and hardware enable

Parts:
C701, C703, C717, C718: 100n 50V; C_0603_1608Metric; MPN C0603C104K5RACTU
C702: 47n 50V; C_0603_1608Metric; MPN C0603C473K5RACTU
C705: 10n 50V; C_0603_1608Metric; MPN C0603C103K5RACTU
D704: PESD5V0S1BA; D_SOD-323; MPN PESD5V0S1BA,115
J703: HW ENABLE; PinHeader_1x02_P2.54mm_Vertical; MPN M20-9990245
JP704: RUN 1-2 / SERVICE 2-3; PinHeader_1x03_P2.54mm_Vertical; MPN M20-9990345
R701, R703: 0; R_0603_1608Metric; MPN RC0603JR-070RL
R702, R720, R722: 10k; R_0603_1608Metric; MPN RC0603FR-0710KL
R704: 100k; R_0603_1608Metric; MPN RC0603FR-07100KL
R721: 1k; R_0603_1608Metric; MPN RC0603FR-071KL
U701: TPS389033DSER; WSON-6_1.5x1.5mm_P0.5mm; MPN TPS389033DSER
U702: TPS3431SDRBR; VSON-8-1EP_3x3mm_P0.65mm_EP1.65x2.4mm; MPN TPS3431SDRBR
U710: SN74LVC1G14DBVR; SOT-23-5; MPN SN74LVC1G14DBVR

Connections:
3V3: C701.1, C703.1, C717.1, C718.1, JP704.1, R702.1, R720.1, R722.1, U701.3 (nMR), U701.4 (VDD), U702.1 (VDD), U702.3 (EN), U710.5 (VCC); also elsewhere on the board
3V3_A: U701.1 (SENSE); also elsewhere on the board
/16_supervisor/POR_CT: C702.1, U701.5 (CT)
/16_supervisor/POWER_OK: R701.2, U701.6 (nRESET)
/16_supervisor/WD_CWD: R702.2, U702.2 (CWD)
/16_supervisor/WD_OK: R703.2, U702.7 (nWDO)
HW_ENABLE_OK: U710.4; also elsewhere on the board
NRST: R701.1, R703.1; also elsewhere on the board
WD_HEARTBEAT: R704.1, U702.6 (WDI); also elsewhere on the board
WD_RUN: JP704.2, R722.2, U702.5 (SET1); also elsewhere on the board
nHW_ENABLE_FILT: C705.1, R721.2, U710.2; also elsewhere on the board

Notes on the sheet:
Reset, watchdog and hardware enable
Power-on reset and watchdog
Open-drain reset outputs share NRST through zero-ohm links. R504 on the MCU sheet provides the pull-up.
Service and hardware enable
RUN 1-2 / SERVICE 2-3. SERVICE or a chopper fault forces both driver-enable and bridge-arm paths off.

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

Board: 4 copper layers, 116.0 x 112.0 mm, 449 parts (0 on the bottom side), 245 nets.

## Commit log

2026-09-27 devlog 01
    [01_dc_link.kicad_sch, 02_bridge.kicad_sch, 03_regen.kicad_sch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]
2026-09-28 devlog 02
    [01_dc_link.kicad_sch, 02_bridge.kicad_sch, 05_mcu.kicad_sch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]
2026-09-28 devlog 03
    [01_dc_link.kicad_sch, 02_bridge.kicad_sch, 03_regen.kicad_sch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]
2026-09-28 devlog 04
    [01_dc_link.kicad_sch, 02_bridge.kicad_sch, 03_regen.kicad_sch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]
2026-09-29 devlog 05
    [bldc-esc.kicad_pcb, requirements.csv, review_gates.csv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]
2026-09-29 devlog 06
    [bldc-esc.kicad_pcb]
2026-10-05 Sync BLDC-ESC from Half Life
2026-10-06 route gate driver and bridge
    [bldc-esc.kicad_pcb, bom.csv, bom_audit.csv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]
2026-10-07 route brake power and gate connections
    [bldc-esc.kicad_pcb]
2026-10-07 route buck converter and 5v feed
    [bldc-esc.kicad_pcb]
2026-10-07 route usb power and logic supplies
    [bldc-esc.kicad_pcb]
2026-10-07 route pwm and driver controls
    [bldc-esc.kicad_pcb]
2026-10-08 route safety logic and analog power
    [bldc-esc.kicad_pcb]
2026-10-08 route current feedback and reference rails
    [bldc-esc.kicad_pcb]
2026-10-09 route driver current diagnostics
    [bldc-esc.kicad_pcb]
2026-10-09 route voltage and temperature sensing
    [bldc-esc.kicad_pcb]
2026-10-09 route brake controls and power branches
    [bldc-esc.kicad_pcb]
2026-10-09 route brake-active status to the mcu
    [bldc-esc.kicad_pcb]
2026-10-09 route brake-current adc to the mcu
    [bldc-esc.kicad_pcb]
2026-10-09 route hall and encoder interfaces
    [bldc-esc.kicad_pcb]
2026-10-10 route throttle and digital control inputs
    [bldc-esc.kicad_pcb]
2026-10-10 connect boot controls and local supply branches
    [bldc-esc.kicad_pcb]
2026-10-10 replace the diagram with a pcb render
2026-10-10 route the CAN connector and termination
    [bldc-esc.kicad_pcb]
2026-10-10 connect the bridge test points and snubbers
    [01_dc_link.kicad_sch, 02_bridge.kicad_sch, bldc-esc.kicad_pcb]
2026-10-10 connect the external clock
    [bldc-esc.kicad_pcb]
2026-10-10 connect USB protection and EEPROM power
    [bldc-esc.kicad_pcb]
2026-10-11 add mounting holes and bring-up firmware
2026-10-11 switch fabrication settings to pcbway
2026-10-11 prepare top stencil and correct pcbway quote
2026-10-11 update assembly notes and full purchasing bom
